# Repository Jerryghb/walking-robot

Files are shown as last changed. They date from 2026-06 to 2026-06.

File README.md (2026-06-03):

# Multi-Legged Walking Robot (Theo Jansen Mechanism)




<!-- 📸 Hero Image Placeholder: Upload your best full-body photo of the final robot here -->


## 📖 Project Background

This project focuses on the design and fabrication of a bio-inspired multi-legged walking robot using the **Theo Jansen linkage mechanism**. The core objective of this robot is to demonstrate how simple linkage systems can be used for practical tasks, specifically by maintaining stable locomotion while carrying a payload (approximately 200g - 220g, equivalent to a small milk bottle) across different surfaces. 

Unlike wheeled robots that rely on rolling, the Jansen mechanism translates continuous rotary motion into a stepping action, allowing for efficient movement on uneven surfaces.

## ✨ Key Features

* **Bio-Inspired Locomotion:** Utilises a one-degree-of-freedom Jansen linkage system (eight rigid links and seven revolute joints per leg) to simulate an animal's step cycle.
* **Lightweight & Robust Body:** The primary structural components are laser-cut from 3mm acrylic plates, providing an optimal balance of strength and low weight (approx. 250g total weight).
* **Custom Payload Carrier:** Features a specially designed 3D-printed payload tray to securely hold a 180ml - 220ml milk box during operation.
* **Upgraded Joint Mechanisms:** Replaces standard screw joints with custom shaft locks for smoother, jam-free rotation.
* **Power & Actuation:** Driven by a single DC motor powered by a compact 9V battery.

## 🛠️ Fabrication & Hardware

* **Chassis & Legs:** 3mm transparent acrylic sheets (Laser-cut).
* **Payload Holder & Shafts:** 3D printed custom components.
* **Fasteners:** Inward-oriented screws and shaft locks for a snag-free, clean profile.
* **Power Source:** 9V Battery.
* **Actuator:** Standard DC Motor.

Laser Cutting Design  


<br>
3D Printed Holder  



## 🚀 Development Process & Iterations

The final robot is the result of continuous testing and iteration:

1. **First Prototype:** Built at 2x scale. Proved too heavy and required excessive torque for the initial 3V (2x AA) power source.
   

2. **Second Prototype:** Scaled down to the original dimensions. Revealed weaknesses in joint stability (loose screws) and leg flimsiness (single thin triangular pieces).
   
   
   

3. **Final Product:** * Upgraded to a **9V battery** for sufficient motor torque.
    * Reinforced each leg with **dual triangular pieces** for enhanced lateral stability.
    * Integrated **shaft locks** instead of loose screw joints for smooth rotation.
    * Added the **3D-printed payload holder**.

   

## 📊 Testing and Evaluation

* **Payload Capacity:** Successfully carries a 180ml milk box payload while in motion.
* **Locomotion:** Walks perfectly straight on flat, smooth surfaces. Displays a slight turning deviation on rougher terrain (e.g., carpet) before stabilizing forward movement.
* **Weight:** ~250 grams (including battery and motor).

## 👥 Team Contributors

* **Cù Đình Bách** - Project Leader / Body Design / Documentation
* **Trần Quốc Việt Hải** - Leg Design / Documentation
* **Cao Phương Linh** - Item Holder & Connector Design / Documentation
* **Nguyễn Minh Anh** - Assembly & Testing / Documentation

The project was conducted at RMIT University Vietnam with fellow university students.

## 📚 References

1. wolfCat workshop, “Paper Linkages Part 6 - Jansen’s Linkage,” *Youtube*. [Link](https://www.youtube.com/shorts/PBuOBGfEzXk)
2. Wikipedia Contributors, “Jansen’s linkage,” *Wikipedia*. [Link](https://en.wikipedia.org/wiki/Jansen%27s_linkage)
3. Rohit John Varghese, “Stair-Ascending Strandbeest,” *The University of Texas at Austin*. [Link](https://cloud.wikis.utexas.edu/wiki/spaces/RMD/pages/51054238/10+-+Stair-Ascending+Strandbeest)

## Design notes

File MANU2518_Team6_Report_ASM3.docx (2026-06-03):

MANU2518 – Advanced Manufacturing and Mechatronics

ASM3 – Practical Assignment

Student group 6

Cù Đình Bách - s4080405

Trần Quốc Việt Hải - s4134271

Cao Phương Linh – s4136220

Nguyễn Minh Anh – s4103697

# 1 Introduction

## 1.1 Project Background

This project focuses on the design and fabrication of a multi-legged walking robot using the Theo Jansen linkage mechanism. A key requirement of the design is its ability to carry a payload with a weight of around 200g while maintaining a stable moving motion.

Ultimately, this project needs to serve as a practical study of bio-inspired robotic locomotion and as a demonstration of how simple linkage systems can be used in real tasks, including carrying loads and crossing obstacles.

## 1.2 Project purpose

The purpose of this project is to design and fabricate a four-legged walking robot using the Theo Jansen mechanism.

The robot will be constructed primarily from 3mm acrylic sheets through laser cutting, ensuring ease of fabrication and accuracy in part geometry. It will be powered by compact batteries (9-volt battery).

A central design requirement is the robot’s ability to carry a payload equivalent to a 220 g milk bottle.

This project also reflects our understanding of mechanical linkages, material selection, and design optimization. It shows our ability to apply theoretical knowledge to practical problems and to use simple fabrication methods to create a working prototype. In addition, the project demonstrates our skills in teamwork, problem solving, and testing, which are all important for future engineering practice.

## 1.3 Literature review

The Jansen mechanism, also referred to as the Jansen linkage, is a planar linkage system originally developed by Dutch artist Theo Jansen for his Strandbeest creations [1].

The Jansen mechanism is a one-degree-of-freedom system that uses eight rigid links and seven revolute joints. Together, these parts change continuous rotary motion into a walking pattern. The design is based on triangular linkages that turn the crankshaft input into a smooth foot path that looks like the step cycle of animals [2].

Each leg is made of several segments connected by pivoting joints. When the crank rotates, the rocker arms move back and forth, sending motion to the transmission links, which then drive the lower leg segments. This creates a closed foot path with two main phases. The stance phase is when the foot is on the ground, giving support and pushing the body forward. The swing phase is when the foot is lifted to clear the ground. Unlike wheels, which rely on rolling, this mechanism allows an efficient stepping action on soil, sand, or uneven surfaces.

From an engineering view, the Jansen mechanism is simple and easy to scale [3]. With only one crank input per leg, many legs can be linked together using shafts, gears, or belts. This means that even complex robots can work with only a small number of actuators. The mix of efficiency, simplicity, and bio-inspired movement explains why the Jansen mechanism is often studied in robotics as a good balance between design and performance.

# 1 Design Requirements

The design of the multi-legged walking robot is governed by a set of functional and fabrication requirements to ensure manufacturability, reliability, and performance under specified conditions. These requirements are summarized as follows, and some crucial requirements are detailed below:

- Lightweight, optimized material used as well as design
- Be able to walk straight smoothly and steadily with good balance
- Be able to carry 200-220g of payload without reduction in performance
- Laser-cut, 3D printed parts should have good fitting cuts, joints secure and stable
- The speed of the robot should be fast and smooth with efficient operation
- Design of robot should be creative with upgrade in functionality and aesthetics

## 1.1 Fabrication Method

Most structural components must be laser-cut. The stock material is 3 mm acrylic plates, which ensures ease of machining and consistent thickness. Additional parts of different thicknesses may be sourced from external vendors if required.

All parts must be arranged within a single 2D drawing file (saved in *.DXF format) for efficient cutting.

A minimum spacing of 1 mm between adjacent parts in the cutting layout must be maintained to avoid damage or interference during laser cutting.

## 1.2 Power Source

The robot should be powered by batteries that provide sufficient power for the motor (the maximum voltage that the motor can handle is 9 volts). The battery will be housed in an enclosure on the robot, it must be portable, lightweight, and fit somewhere on the robot. There should be a switch for turning the robot on and off.

## 1.3 Payload Capacity

The robot must be able to carry a payload of approximately 200–220 grams, equivalent to the weight of a small milk bottle.

## 1.4 Test Conditions and Locomotion Requirements

The robot, while carrying the payload, must demonstrate stable walking motion across the carpeted classroom floor for about 40 to 60 cm.

# 2 First Prototype

## 2.1 Process

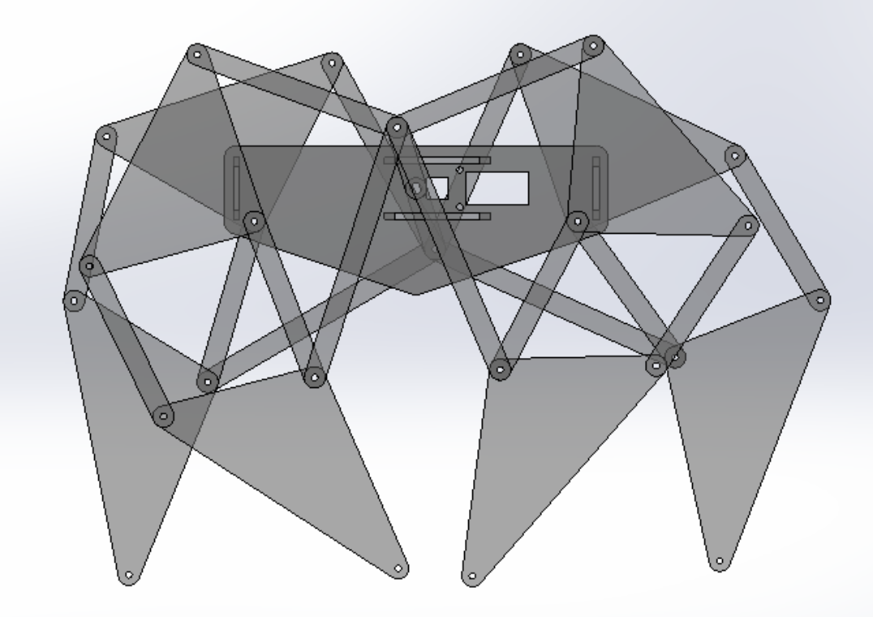
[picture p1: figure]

Figure 1: Side view of first prototype’s CAD model

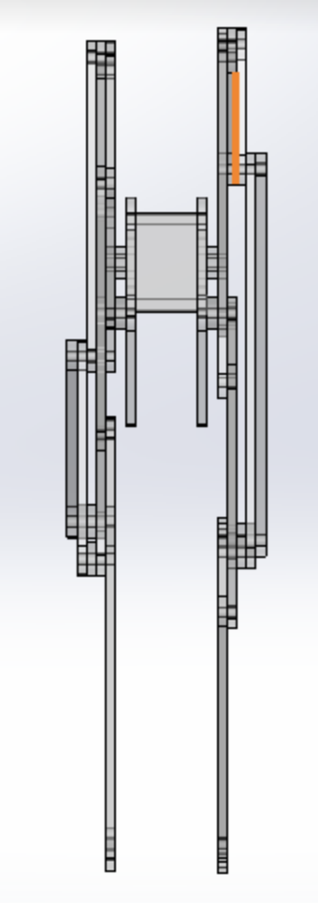
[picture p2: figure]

Figure 2: Front view of first prototype’s CAD model

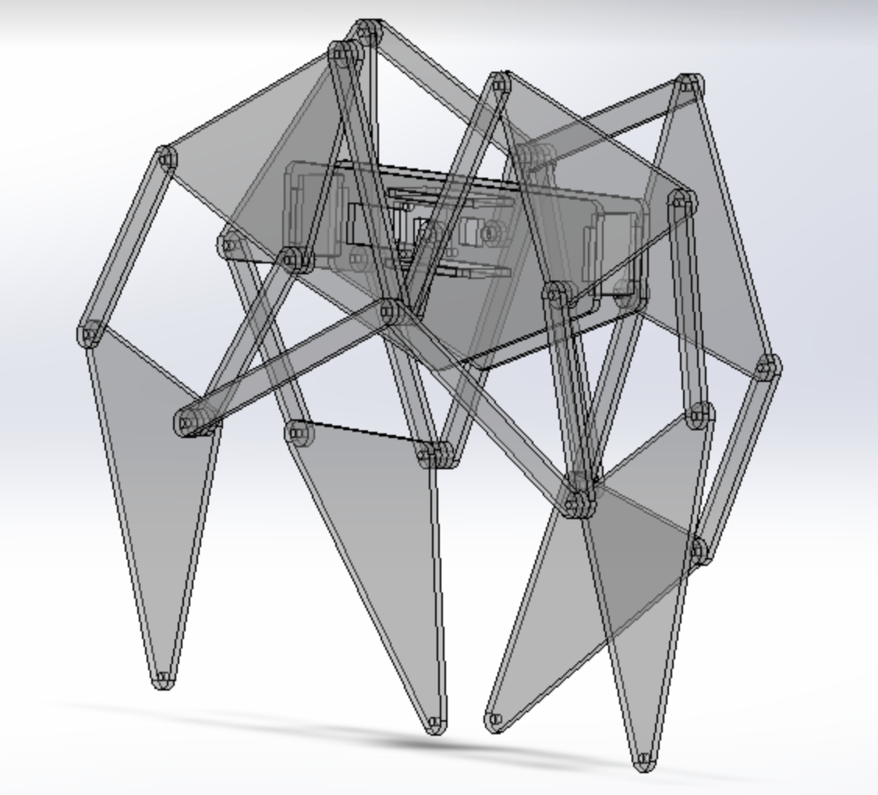
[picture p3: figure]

Figure 3: CAD model of first prototype’s full robot assembly

For the first prototype, we used a multiple of the dimensions provided in the assessment requirements file. All dimensions were multiplied by 2 to make the robot bigger, making it too heavy for our single. We expected it to be more stable; however it brought challenges regarding the torque provided by the single motor, which at the time was powered by 2 AA batteries (1.5 Volts).

## 2.2 Improvements / Modifications

For improving this first prototype, we intended to reduce the size of robot to orginal scale. We were also looking for using difference batery for more stability.

# 3 Second Prototype

## 3.1 Process

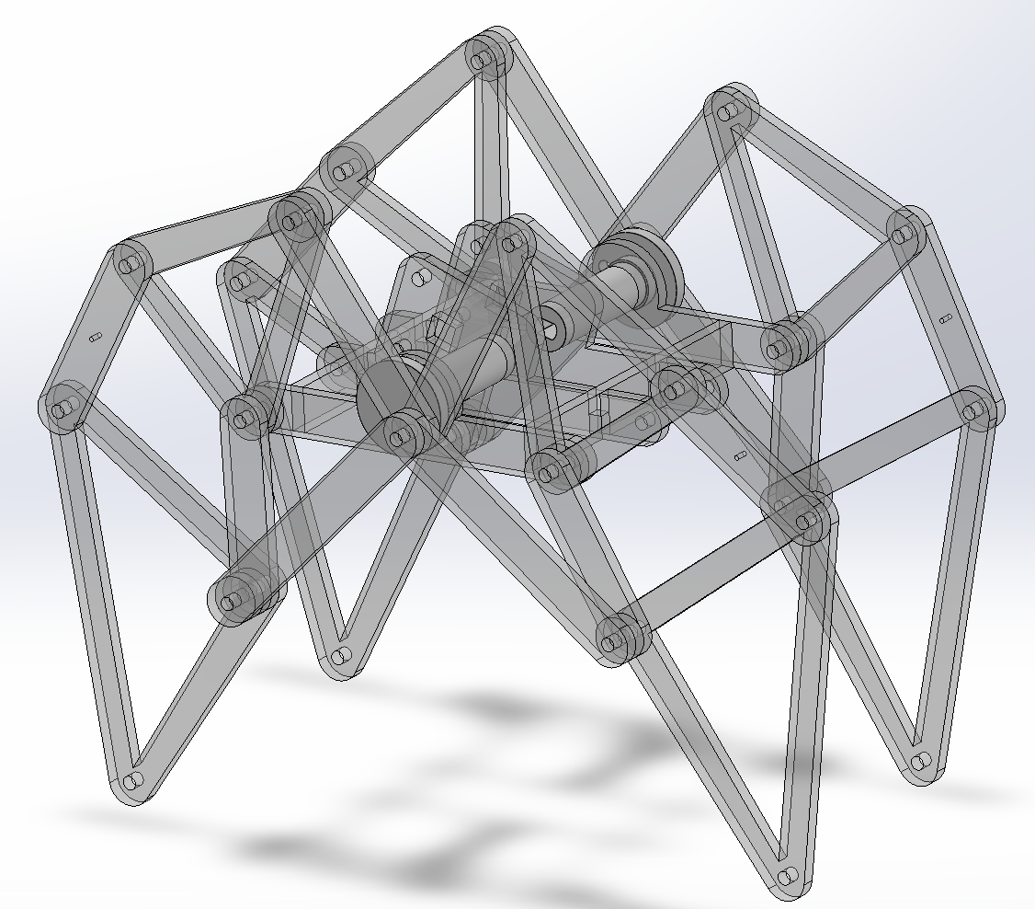
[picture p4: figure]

Figure 4: CAD model of second prototype’s full robot assembly

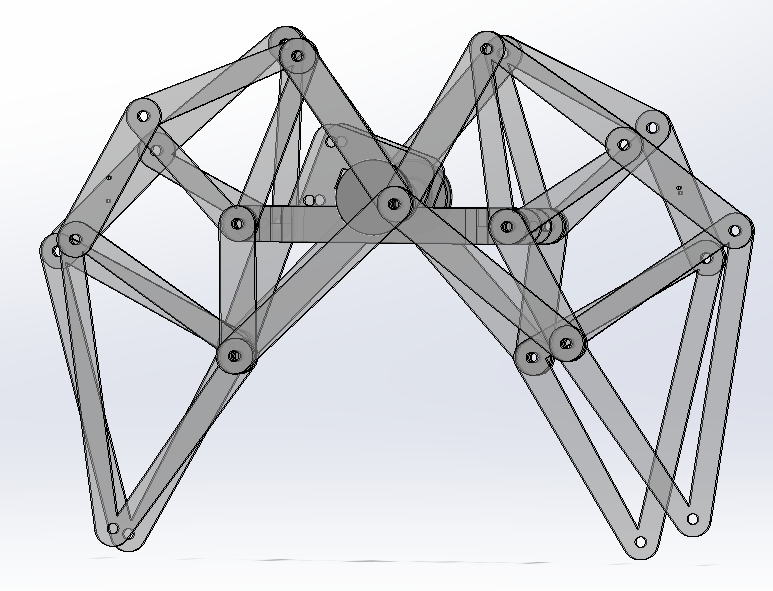
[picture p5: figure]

Figure 5: Side view of second prototype’s CAD model

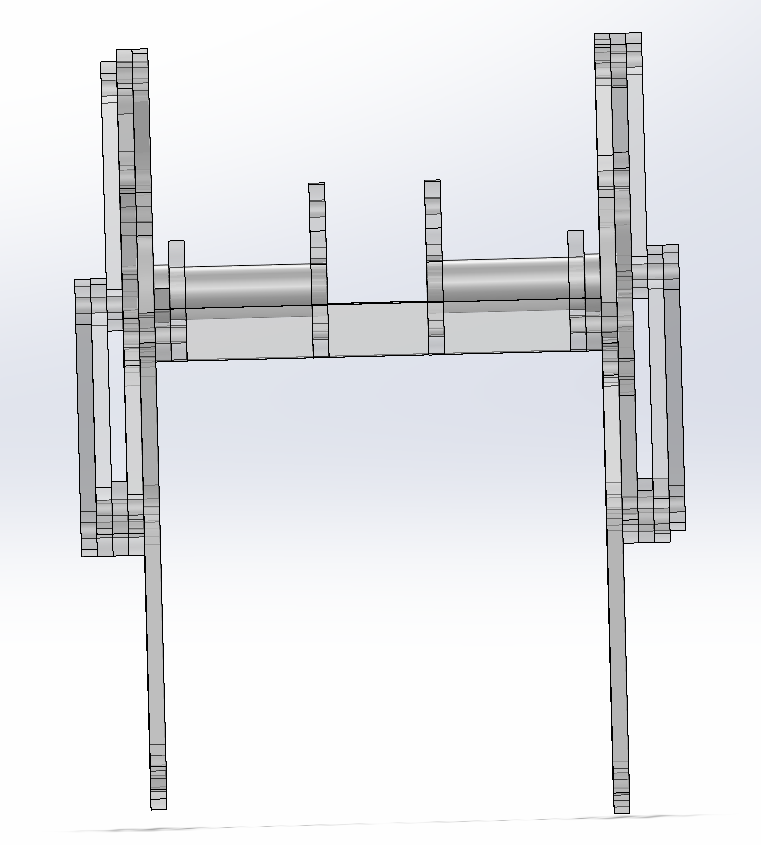
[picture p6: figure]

Figure 6: Front view of second prototype’s CAD model

For this prototype, our team already design to the original size, We also redesigned the shaft connections, replacing the previous loose screw joints with a more stable locking system.

## 3.2 Improvements / Modifications

The second prototype still had many weaknesses:

- Used screws to join the joints → some joints jam and others become loose during rotation.
- Powered by two AA (1.5 V) batteries → movement is too slow.
- No place to mount a payload.
- Each leg uses only one thin triangular piece → legs are flimsy and wobble, so the robot cannot walk straight.
- Screws protrude outward → cause interference and snagging.

To improve this prototype, we planned to replace screws with shaft locks so the joints would be more secure and rotate smoothly. We switched to a 9-volt battery, add a 3D-printed part for the payload, and reinforce each leg with two triangular pieces for better stability. In addition, the screws were turned inward for a neater design. With these changes, we hoped the robot would move faster, walk more steadily, and carry small loads effectively.

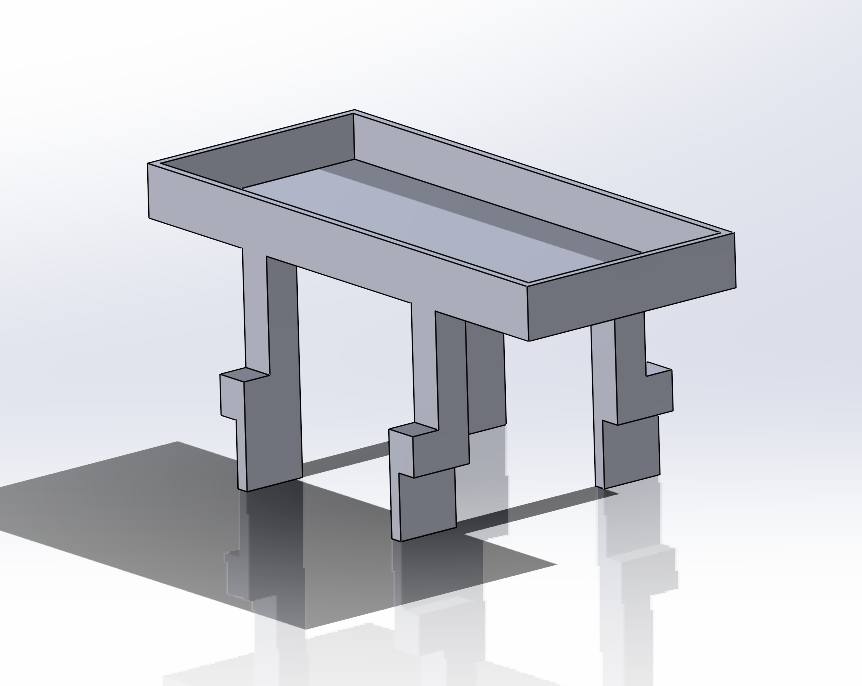
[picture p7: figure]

Figure 7: Carrying tray for the payload (milk box)

# 4 Final Product

In our final product, our group implemented several technical upgrades to improve both performance and design. We replaced screws with shaft locks to ensure stronger and smoother joint connection and switched to a 9V battery to provide more power to the motor. A custom 3D-printed component was added to support payload placement, while each leg was reinforced with an additional triangular piece to increase stability during locomotion. Finally, we reoriented the screws inward, resulting in a cleaner, more compact, and functional structure.

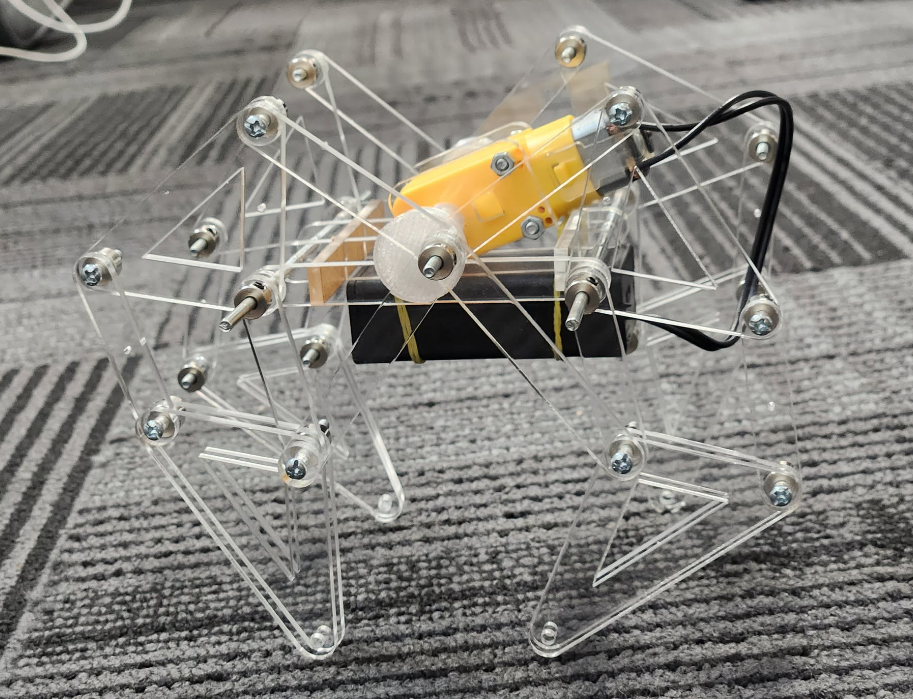
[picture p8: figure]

Figure 8: Final Robot side view

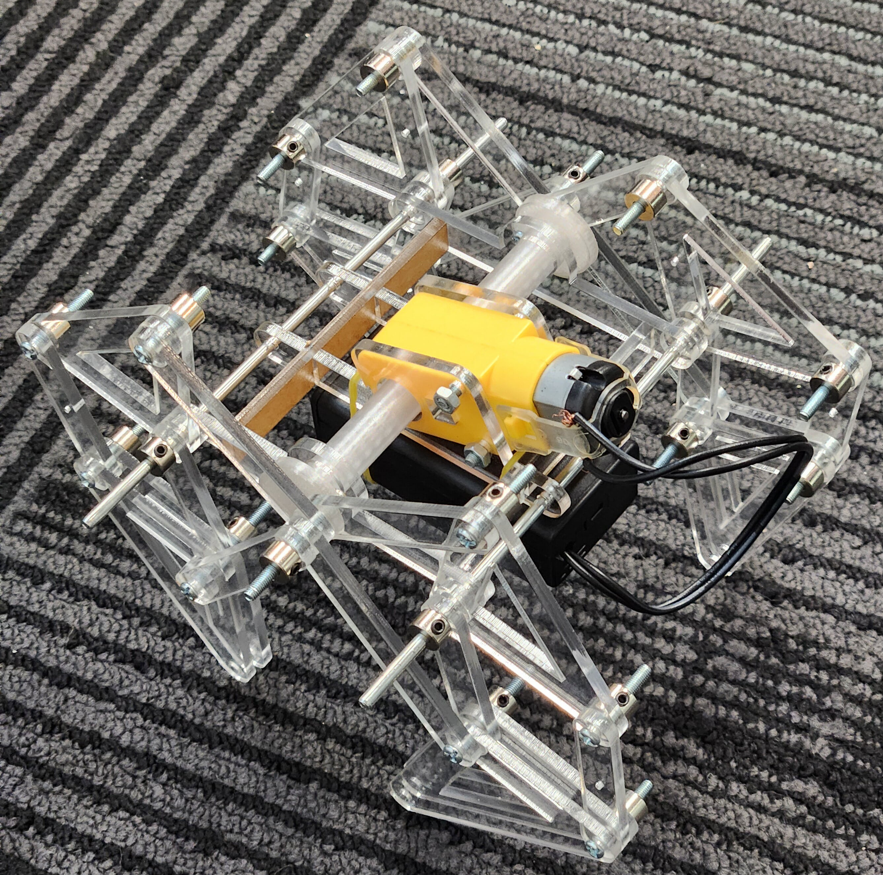
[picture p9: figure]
Không có mô tả.

Figure 9: Final Robot fullbody

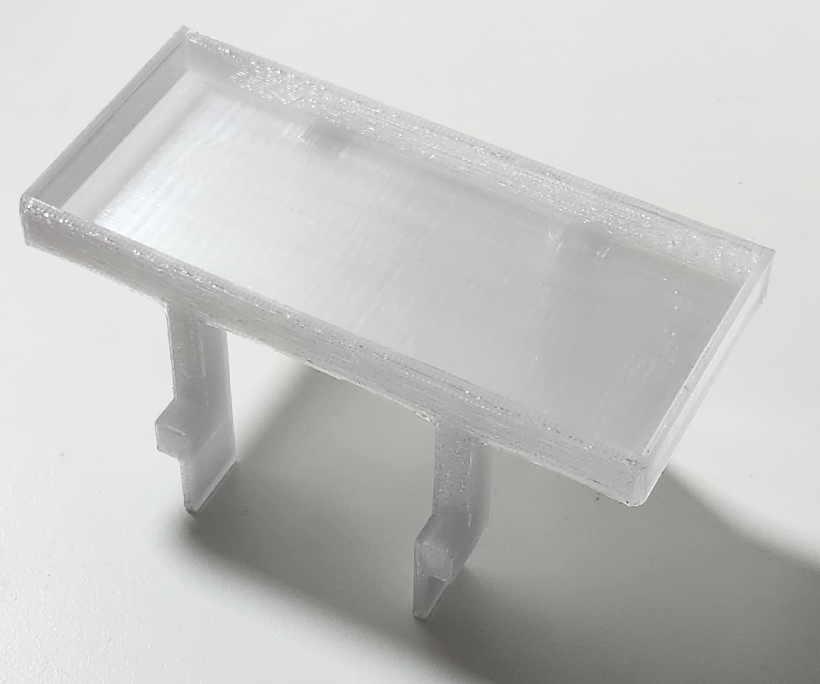
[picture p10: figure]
Không có mô tả.

Figure 10: Final 3D-printed holder, top view

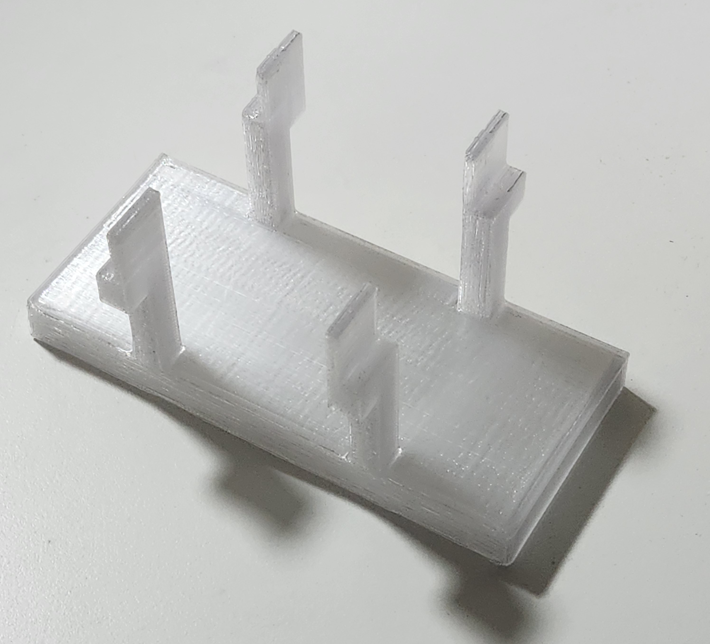
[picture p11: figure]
Không có mô tả.

Figure 11: Final 3D-printed holder, bottom view

## 4.1 CAD Model

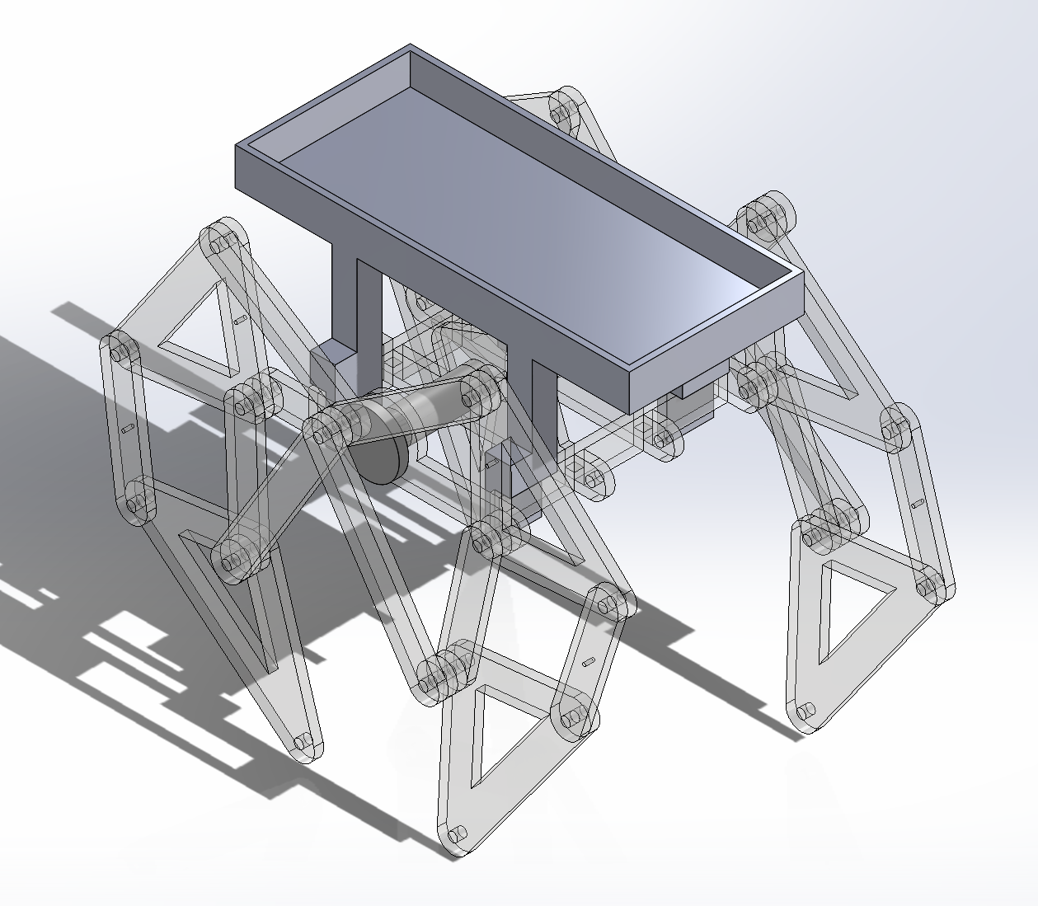
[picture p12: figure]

Figure 12: Final prototype full assembly CAD model

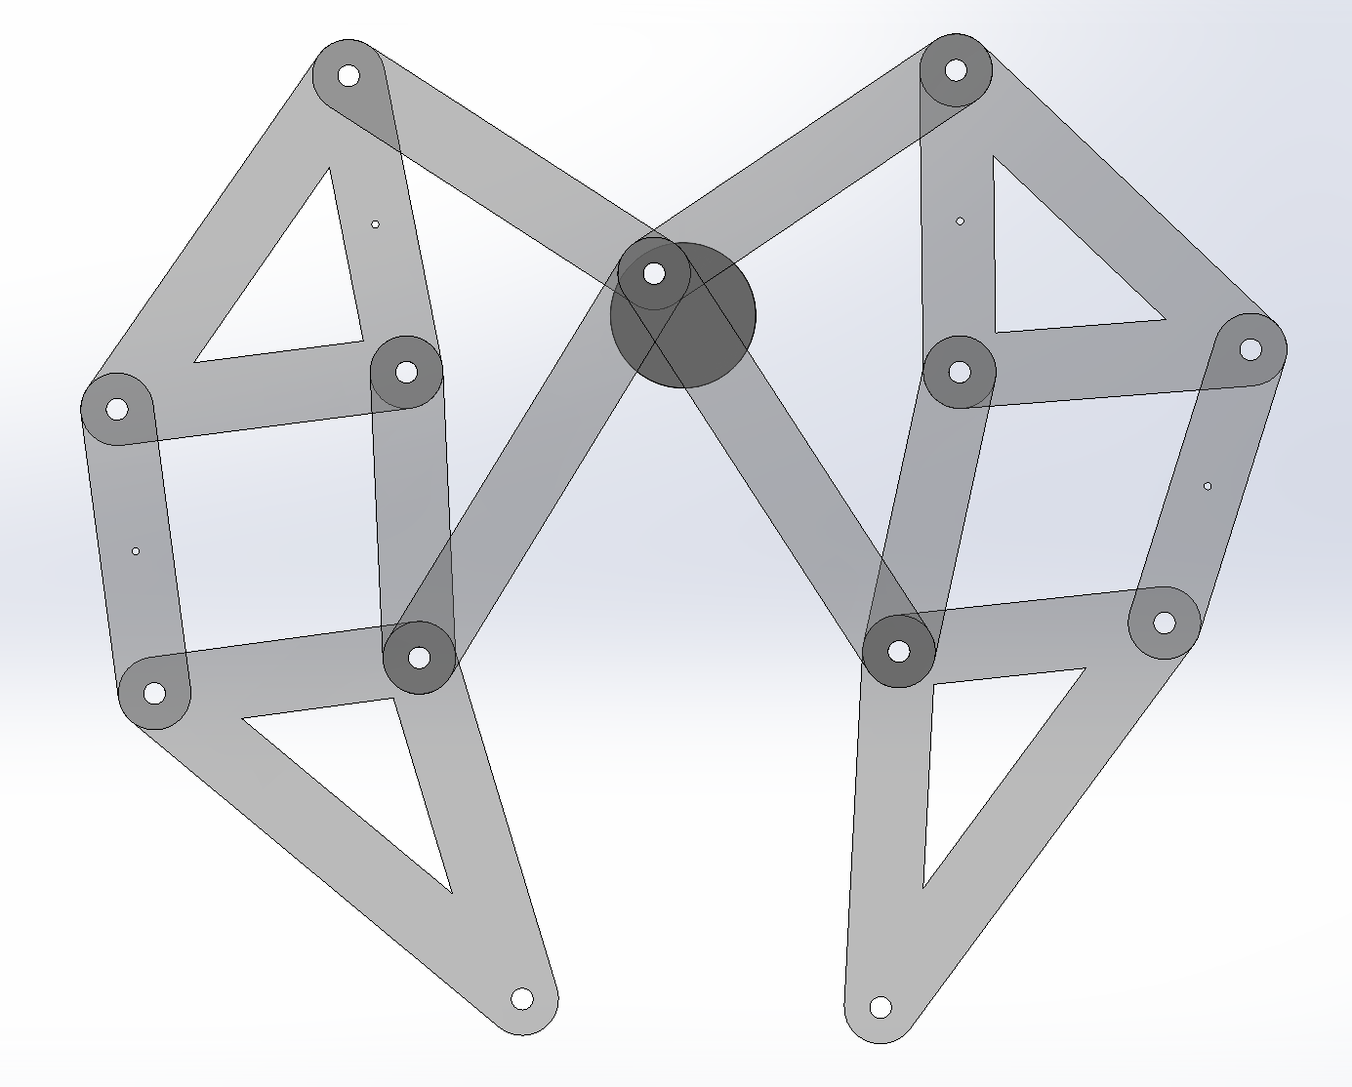
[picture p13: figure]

Figure 13: Final prototype CAD leg assembly side view (1 side)

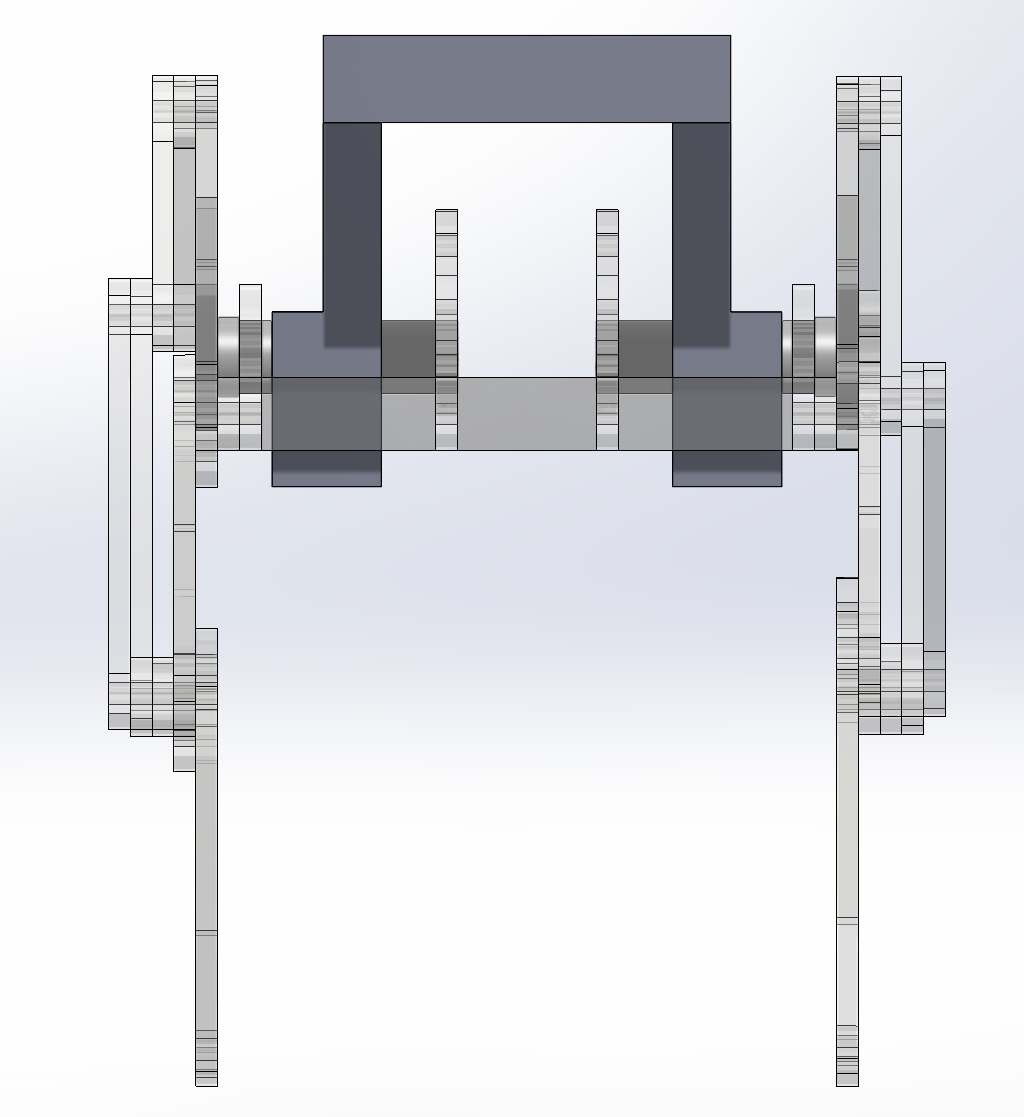
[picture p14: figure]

Figure 14: Final prototype CAD model front view

## 4.2 Laser Cutting and 3D printing layout:

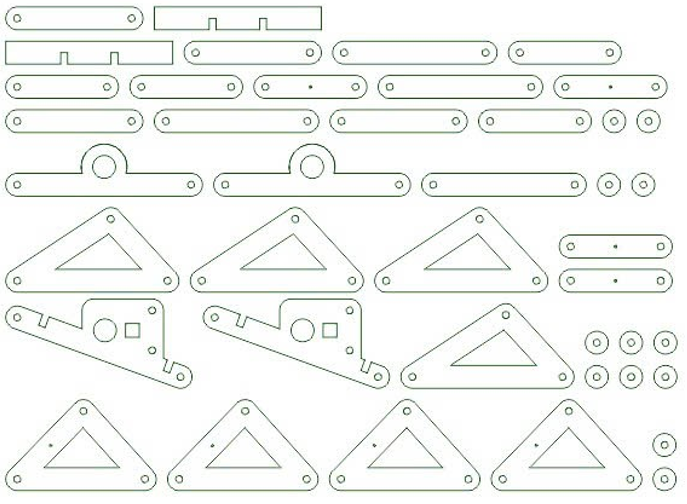
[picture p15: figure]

Figure 15: Final prototype laser cutting design

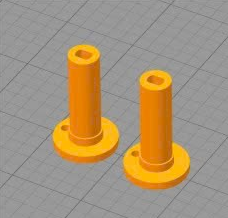
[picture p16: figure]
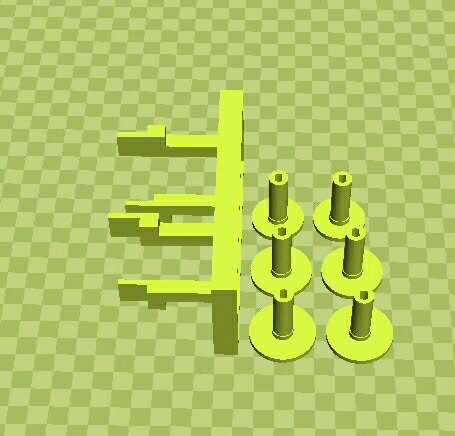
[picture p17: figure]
Không có mô tả.

Figure 16: 3D printer preview of shaft

## 4.3 Assembly Process

The assembly was carried out step by step, from the main body down to the legs:

- Body and connectors: The central body frame was first assembled, and the shaft connectors were attached to hold the motor and axle in place.
- Leg modules: Each leg was built separately using 3 triangular plates and two straight linkages, joined together with screws and shaft locks to form a Jansen linkage.
- Leg–body connection: The completed leg modules were then attached to the body through the shaft connectors, making sure each pair of legs was aligned correctly on both sides.
- Motor installation: The DC motor was mounted on top of the frame and connected to the main axle, providing rotational motion to drive the leg mechanism.
- Holder: The milk holder is placed on top of the shaft connectors of the body for easy removal and attachment for testing.

Final adjustments: All screws were tightened and oriented inward to keep the design neat, and the battery pack was secured beneath the body to complete the assembly.

# 5 Testing and Evaluation

Testing condition: Our testing was conducted on the classroom floor, which was covered with carpet. The robot was required to walk in a straight line for about 40 – 60 cm (equivalent to four carpet tiles). In addition, it needed to carry a 180 ml milk box placed on top as a payload. Our team was allowed to perform two test runs to evaluate this requirement, and the detailed results are presented below.

## 5.1 Fabrication Method

All structural components were fabricated using laser cutting on 3 mm acrylic plates, ensuring consistent geometry and smooth assembly. The parts were arranged in a single DXF cutting layout with proper spacing, and no interference or damage occurred during fabrication.

## 5.2 Power source

This provided stable performance without unexpected shutdowns and delivered enough power for the robot to walk and complete the required test.

## 5.3 Payload Capacity

The final prototype was able to carry a 180 ml milk box on top while moving. On flat and smooth surfaces (such as a table), the robot walked straight as expected. However, when tested on a carpeted surface, the robot initially turned about 180 degrees before continuing to move forward. Overall, the robot performed well on smooth surfaces but showed instability on rough or uneven surfaces such as carpet.

## 5.4 Appearance and weight

The final prototype weighs approximately 250 g, including the battery and motor. Its transparent body gives it a clean and visually appealing look, making the overall design both functional and aesthetically pleasing.

# 6 Conclusion

Through this project, our team successfully designed, built, and tested a walking robot based on the Jansen mechanism. The final prototype, powered by a 9V battery and equipped with a custom holder, was able to carry a 180 ml payload and walk across both flat and carpeted surfaces. While the robot performed reliably on smooth surfaces and met the basic testing requirements, its motion on rough surfaces showed areas for further improvement. Overall, this project gave us valuable hands-on experience in mechanical design, prototyping, and testing, and demonstrated the importance of iteration in engineering development.

# 7 Team Contribution

Member | Task | Contribution | Signature
Hai | Leg Design, Report | 25% | Tran Quoc Viet Hai
Bach | Body Design, Report | 25% | Cu Dinh Bach
Linh | Item Holder + Connector, Report | 25% | Cao Phuong Linh
Anh | Assembly + Testing, Report | 25% | Nguyen Minh Anh

# 8 References

[1] wolfCat workshop, “Paper Linkages Part 6 - Jansen’s Linkage,” Youtube. Jun. 7AD. [Short]. Available: https://www.youtube.com/shorts/PBuOBGfEzXk

[2] Wikipedia Contributors, “Jansen’s linkage,” Wikipedia, May 28, 2019. https://en.wikipedia.org/wiki/Jansen%27s_linkage

[3] Rohit John Varghese, “Stair-Ascending Strandbeest,” The University of Texas at Austin, https://cloud.wikis.utexas.edu/wiki/spaces/RMD/pages/51054238/10+-+Stair-Ascending+Strandbeest

‌

School/Department/Area Unclassified Status: DRAFT Version: 0.1 DocRef: TRIM Document: Document3 Author: Dinh-Son Vu Save Date: 22/09/2025 Page 2 of 3

School of Science, Engineering, and Technology

Title of Report RMIT Classification: Trusted Unclassified

RMIT Classification: Trusted

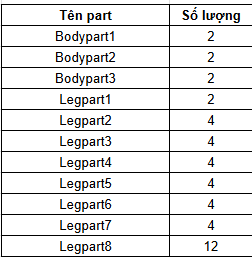
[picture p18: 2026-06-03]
CAD Files/Số lượng part.png

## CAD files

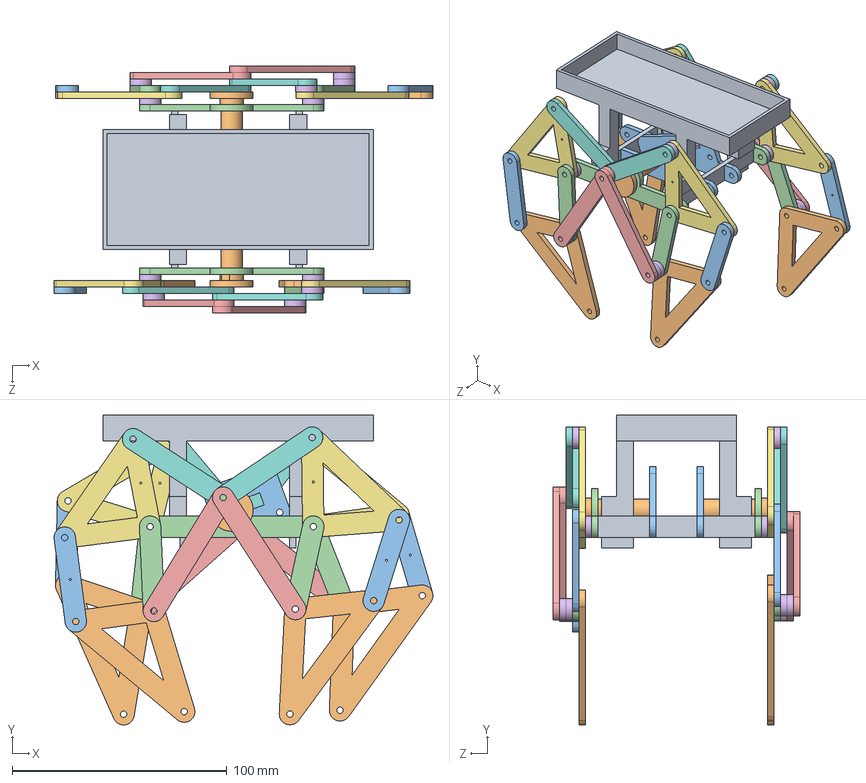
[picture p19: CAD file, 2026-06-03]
CAD Files/Assem1.SLDASM
176.6 x 144.4 x 115.0 mm
Bodypart2 x 2
Bodypart1 x 2
Legpart1 x 2
Bodypart3 x 2
Legpart2 x 4
Legpart6 x 4
Legpart8 x 12
Legpart3 x 4
Legpart4 x 4
Legpart5 x 4
Legpart7 x 4
MilkyTray

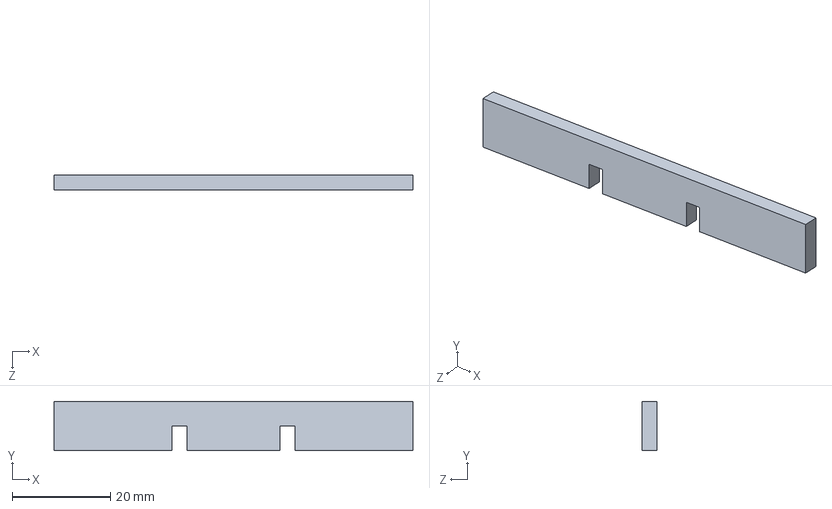
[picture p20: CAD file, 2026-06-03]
CAD Files/Bodypart3.SLDPRT
73.0 x 10.0 x 3.00 mm

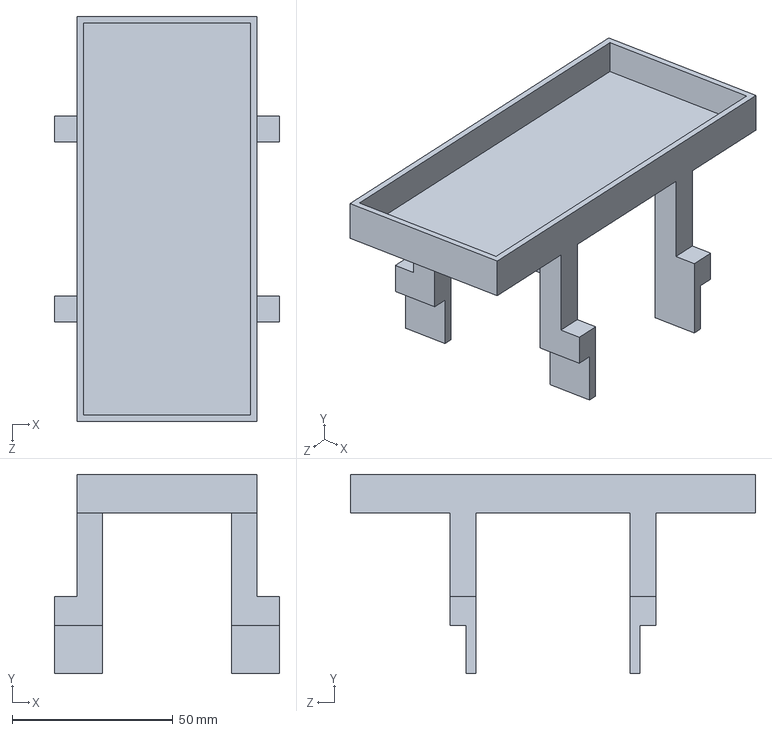
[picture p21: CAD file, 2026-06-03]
CAD Files/MilkyTray.SLDPRT
70.0 x 62.0 x 126.0 mm

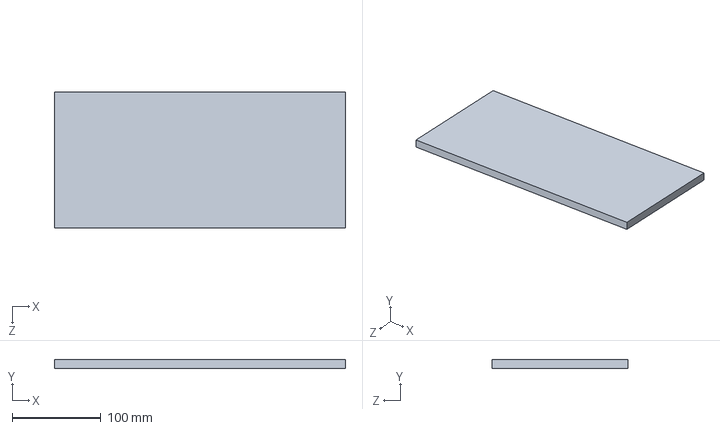
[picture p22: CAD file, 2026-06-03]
CAD Files/TestPlatform.SLDPRT
328.4 x 10.0 x 153.8 mm

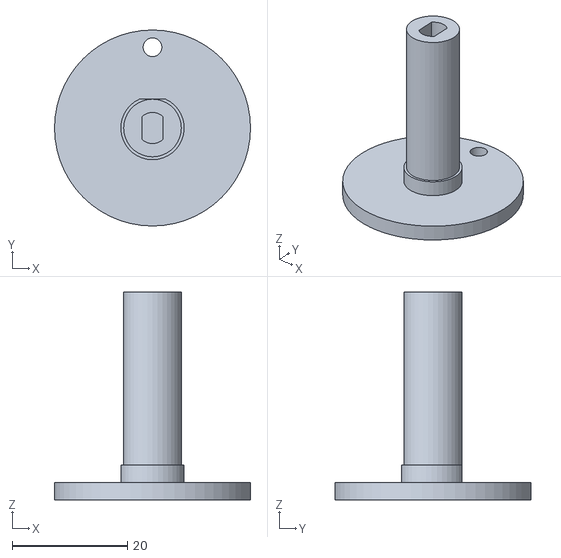
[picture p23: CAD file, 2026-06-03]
CAD Files/Legpart1 34mm.STL
34.0 x 34.0 x 36.0

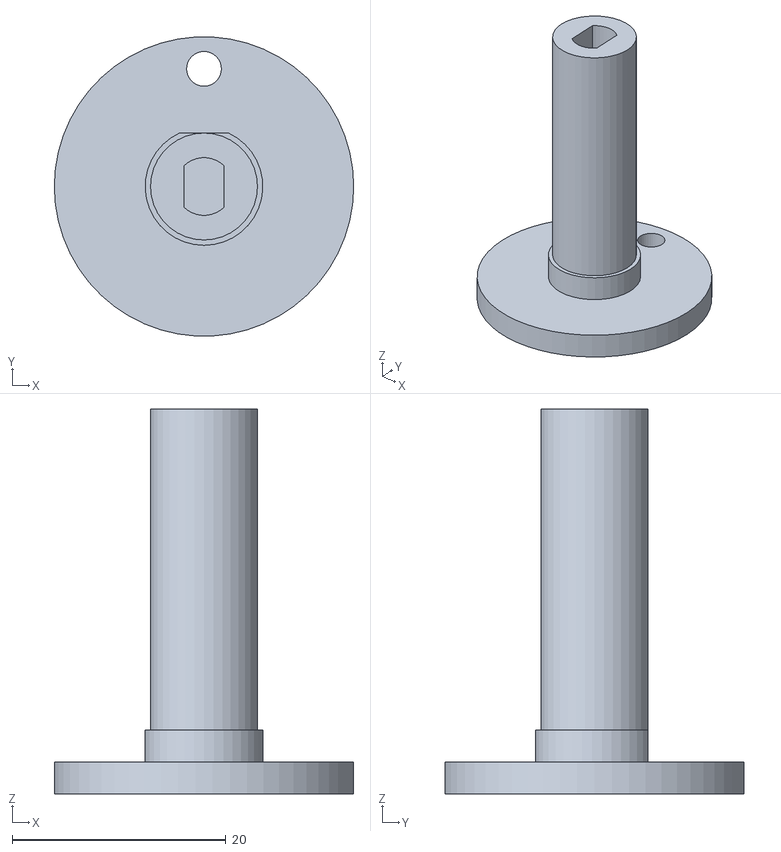
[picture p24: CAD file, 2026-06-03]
CAD Files/Legpart1 28mm.STL
28.0 x 28.0 x 36.0

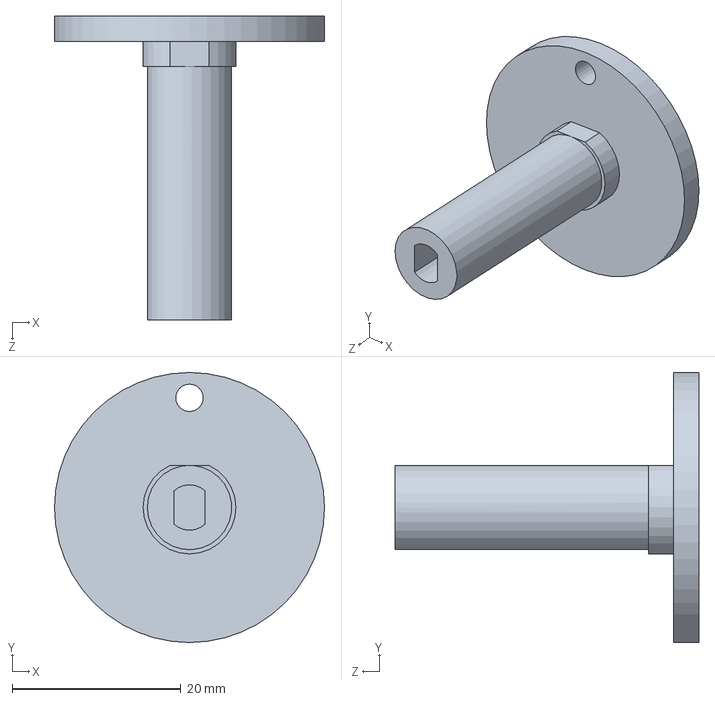
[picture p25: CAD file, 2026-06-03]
CAD Files/Legpart1 32mm.SLDPRT
32.0 x 32.0 x 36.0 mm

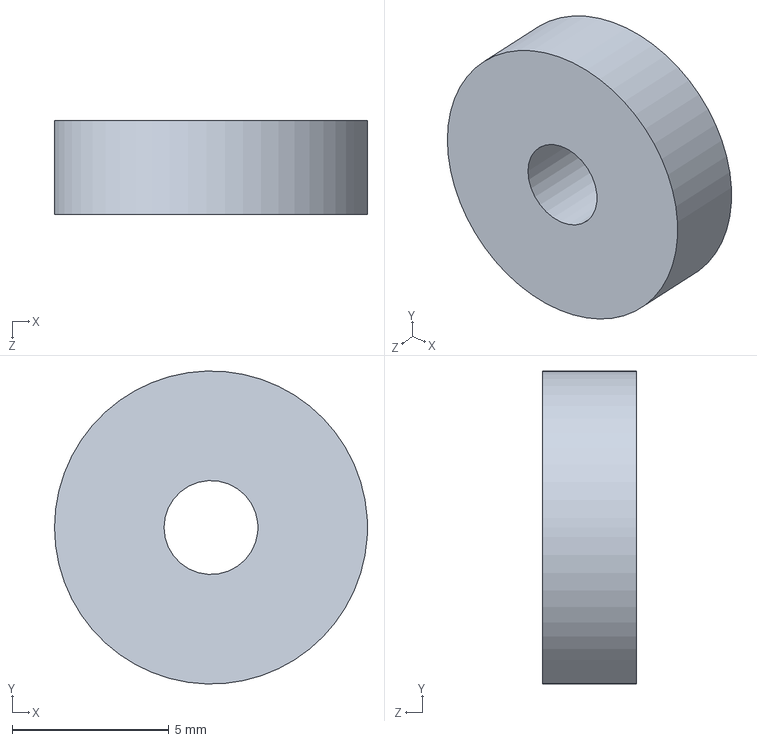
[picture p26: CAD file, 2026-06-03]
CAD Files/Legpart8.SLDPRT
10.0 x 10.00 x 3.00 mm

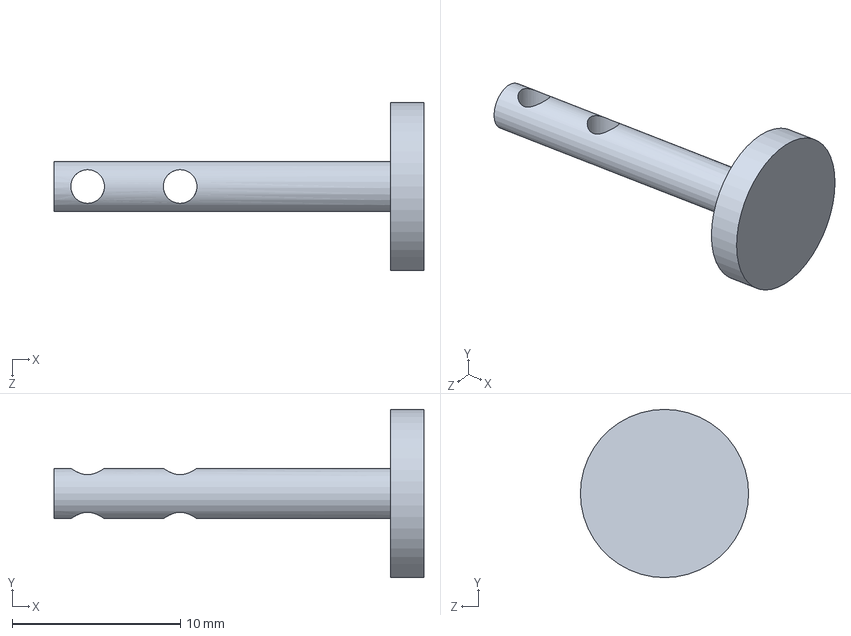
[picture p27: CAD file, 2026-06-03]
CAD Files/Foot.SLDPRT
22.0 x 10.0 x 10.0 mm

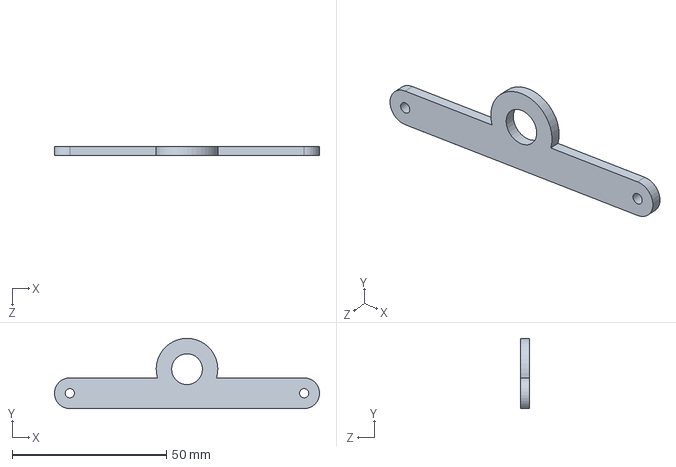
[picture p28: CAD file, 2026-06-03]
CAD Files/Bodypart2.SLDPRT
85.9 x 22.8 x 3.00 mm

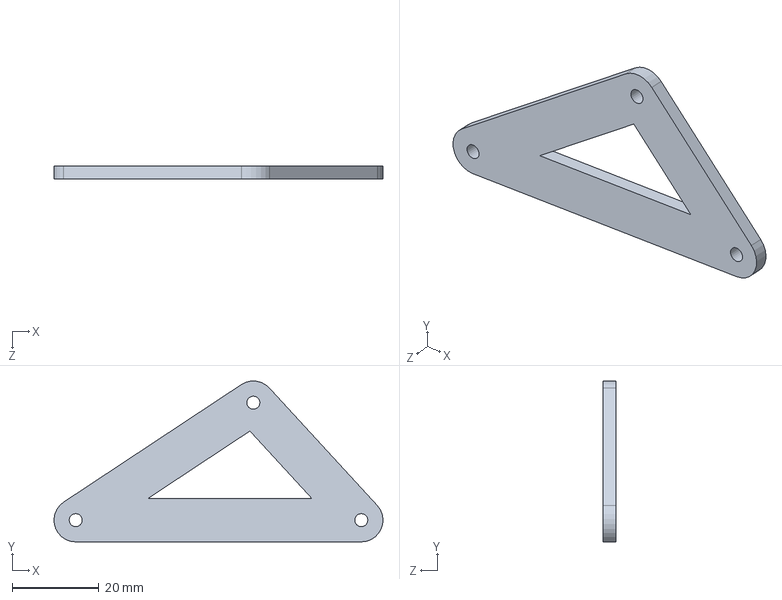
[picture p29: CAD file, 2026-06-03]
CAD Files/Legpart7.SLDPRT
75.7 x 37.0 x 3.00 mm

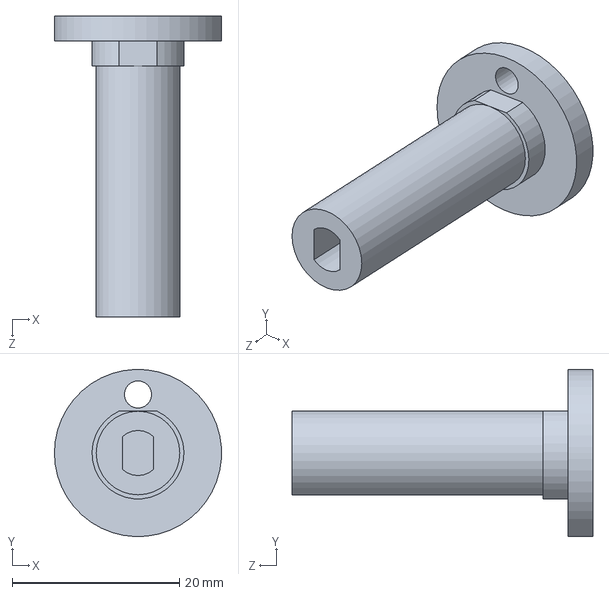
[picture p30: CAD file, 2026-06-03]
CAD Files/Legpart1.SLDPRT
20.0 x 20.0 x 36.0 mm

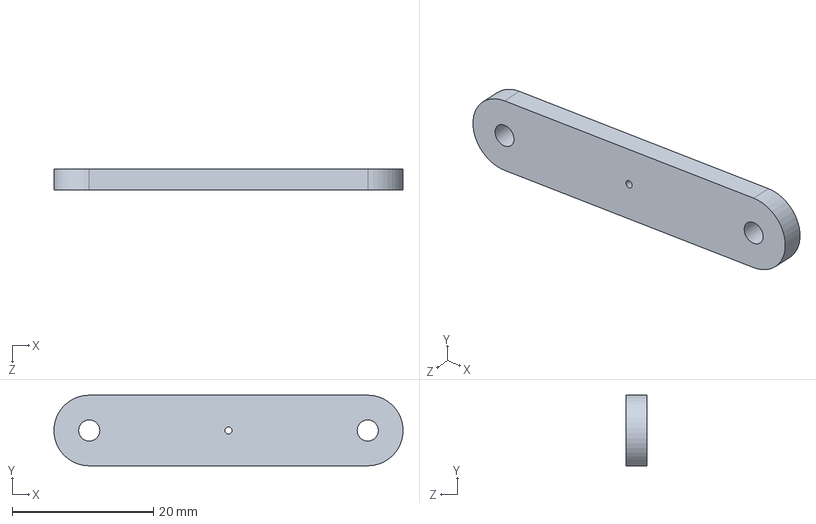
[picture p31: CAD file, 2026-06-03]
CAD Files/Legpart5.SLDPRT
49.4 x 10.0 x 3.00 mm

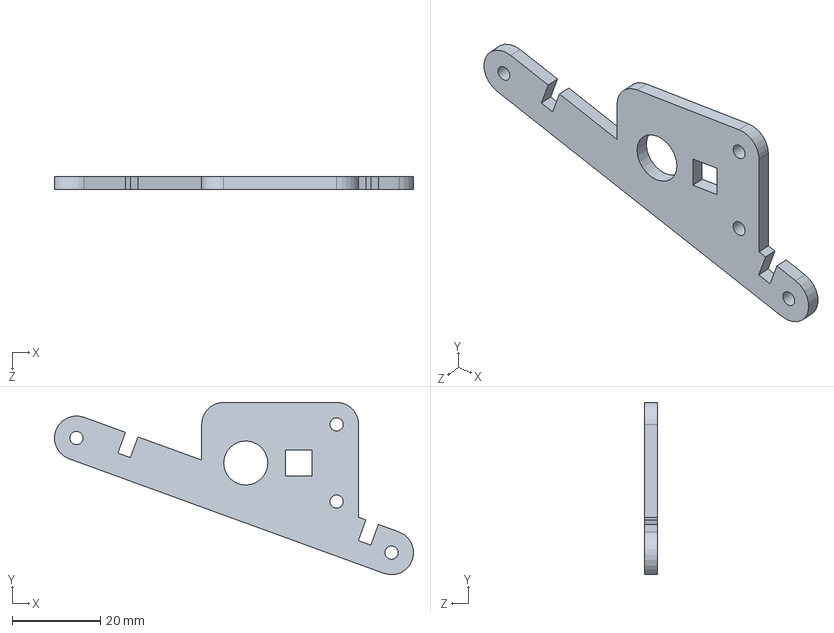
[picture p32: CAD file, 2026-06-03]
CAD Files/Bodypart1.SLDPRT
81.4 x 39.1 x 3.00 mm

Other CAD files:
CAD Files/Legpart4.SLDPRT
CAD Files/Legpart3.SLDPRT
CAD Files/Legpart2.SLDPRT
CAD Files/Legpart6.SLDPRT
CAD Files/Legpart1 32mm.STL
CAD Files/MilkyTray.STL
